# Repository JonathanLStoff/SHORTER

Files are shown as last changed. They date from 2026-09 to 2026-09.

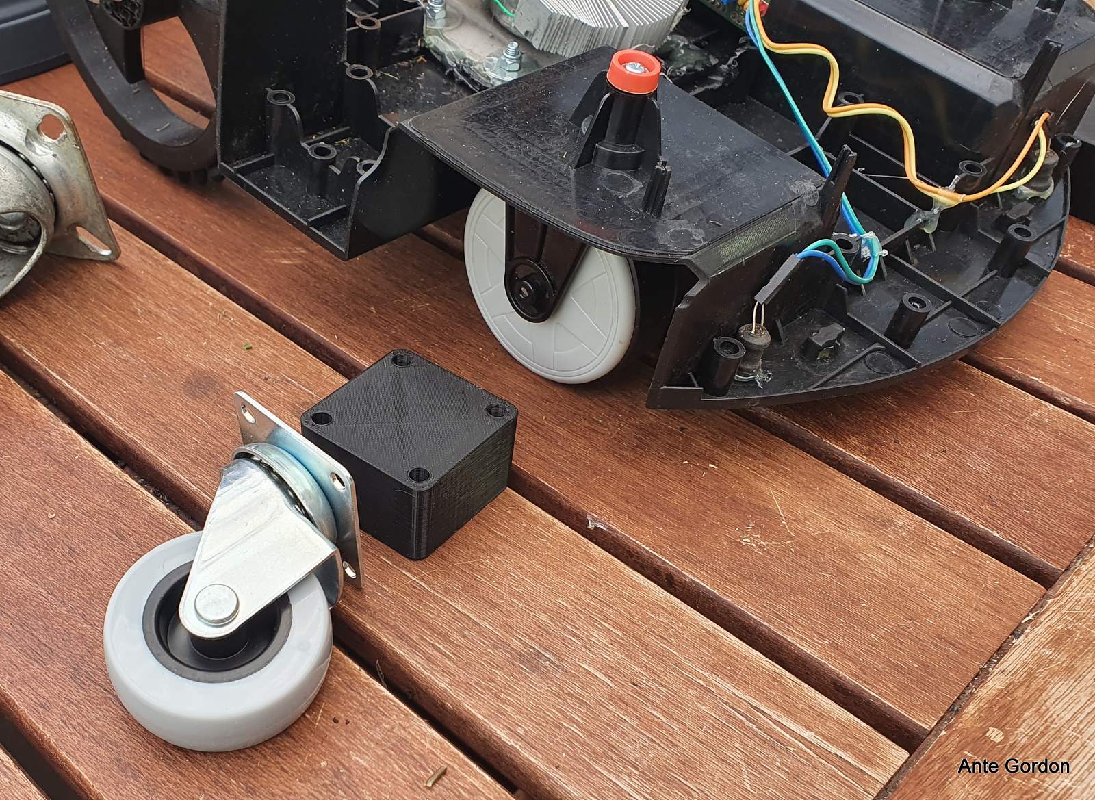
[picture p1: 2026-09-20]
reference/Husqvarna automower mini distanse for Ikea rill wheel - 5445815/images/20220730_103827-1.jpg

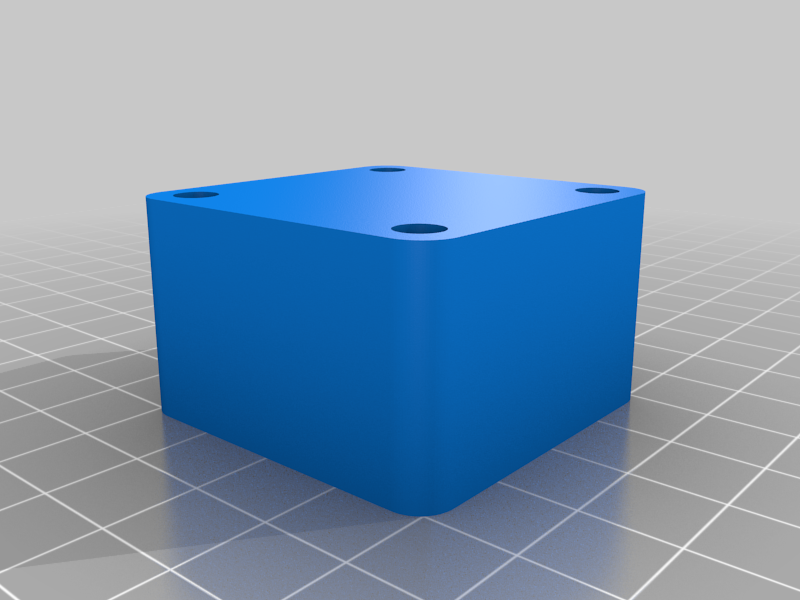
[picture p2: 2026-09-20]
reference/Husqvarna automower mini distanse for Ikea rill wheel - 5445815/images/fr-wheel-rill-25mm.png

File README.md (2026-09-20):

# SHORTER
Sovereign Herbage Ordered Reducer, Trimmer and Eater by Revolution (DIY 3d printable robot lawn mower)

## Possible Parts:

- Acrylic: (dome) https://a.co/d/09qOomaM
- ESP32-C6: https://www.aliexpress.us/item/3256809547014521.html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
- 2x Drive motor TT Motor GM37-3530 or Greartisan 37mm Gear Motor https://www.aliexpress.us/item/3256807619270536.html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
- Blade motor: 12V 775 DC Motor or NFP-RC-545SH https://www.aliexpress.us/item/3256807638419493.html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
- Gyro GY-521 MPU-6050 MPU6050
- 4x+ Bumper: KW12-3 PCB Micro Switch
- Motor controller: BTS7960 https://www.aliexpress.us/item/3256811668284674.html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
- Coil Power Relay DPDT LY2NJ HH62P HHC68A-2Z (fuse?)
- Copper plate for charging
- tinned copper conductor with a thick, high-density polyethylene (HDPE) or heavy-duty PE jacket
- O ring cord 1mm: https://www.aliexpress.us/item/3256812104765869.html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
- filament for waterproof-needing parts (PETG): https://www.amazon.com/SUNLU-Filament-PETG-1-75mm-Stringing/dp/B0FGTQJTM4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
- Buck converter 12v to 5v: https://www.aliexpress.us/item/3256808617601570.html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
- Blades https://a.co/d/00TkhfZo
### Triangulation module:
- NEO-6M GPS Module
- 4x CC1101 915 MHz RF Transceiver Module (1 for robot, 3 for in triangulation)
- 3x ESP32-C3 (For indoor use) https://www.aliexpress.us/item/3256807018729495.html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

### Base Station finder module:
- ESP-32 kit with OV2640: https://www.aliexpress.us/item/3256808099197404.html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
(also using the cc1101 for this)
### Base Station:
- 14.6V 10A LiFePO4 Battery Charger https://a.co/d/04Ycegk0
- QR code
- CC1101 915 MHz RF Transceiver Module
- ESP32-C3 https://www.aliexpress.us/item/3256807018729495.html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
- Acrylic: (dome) https://a.co/d/09qOomaM

### Extras that might be useful:
- Sonic sensor: HC-SR04 HCSR04 (distance sensor/material sensor)
- Wired connectors screws: https://a.co/d/0j6jmUwY || https://www.aliexpress.com/ssr/300000512/BundleDeals2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

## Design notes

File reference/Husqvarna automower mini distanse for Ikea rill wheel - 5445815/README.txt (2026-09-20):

Husqvarna automower mini distanse for Ikea rill wheel by Gigante on Thingiverse: https://www.thingiverse.com/thing:5445815

Summary:
Spacer 25 or 30mm to replace the original caster wheels on the automower toy with Ikea Rill -link wheel. I moved the Liam DIY robotic lawnmower from the 4l food container to the automower RC toy. I had to get more hight due to the small rear wheels (165mm in diameter), and compensate to lift the mower in the front.

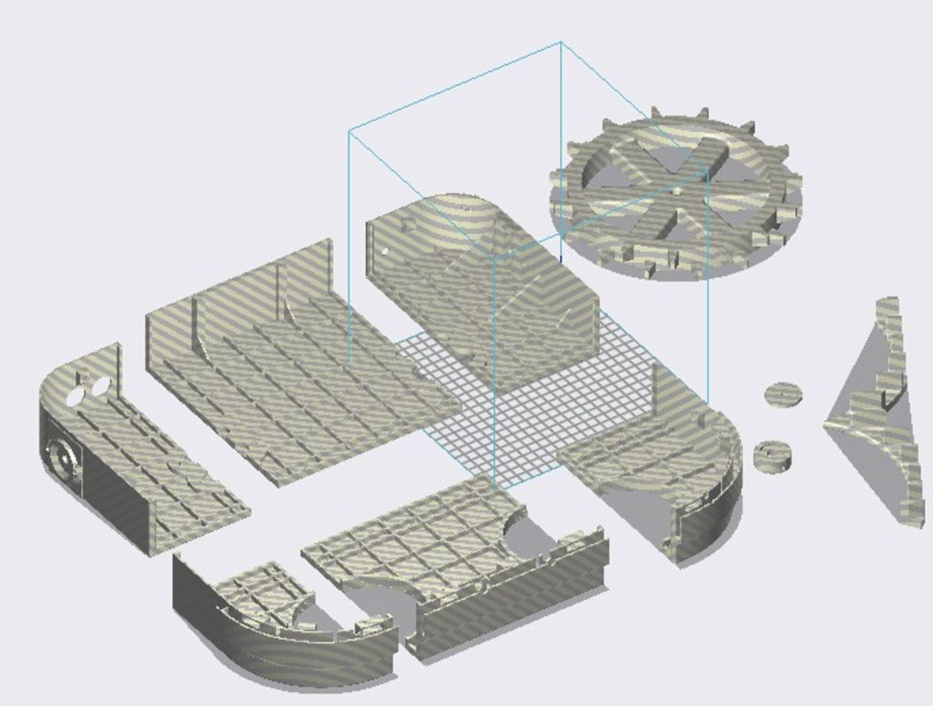
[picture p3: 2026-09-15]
reference/Screenshot 2026-09-14 at 8.23.12 PM.png

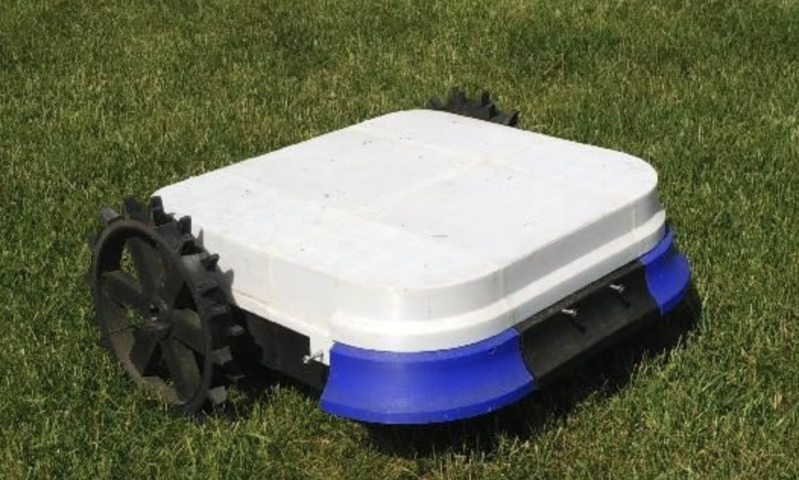
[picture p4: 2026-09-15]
reference/Screenshot 2026-09-14 at 8.22.39 PM.png

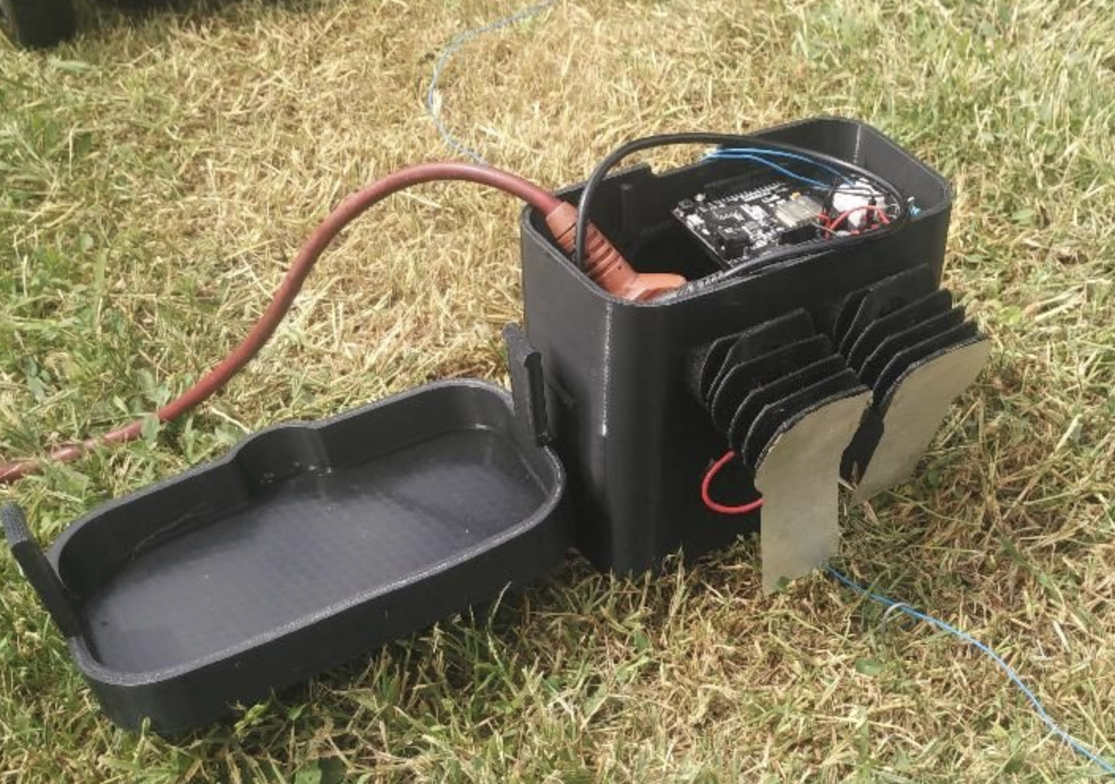
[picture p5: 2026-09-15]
reference/Screenshot 2026-09-14 at 8.23.23 PM.png

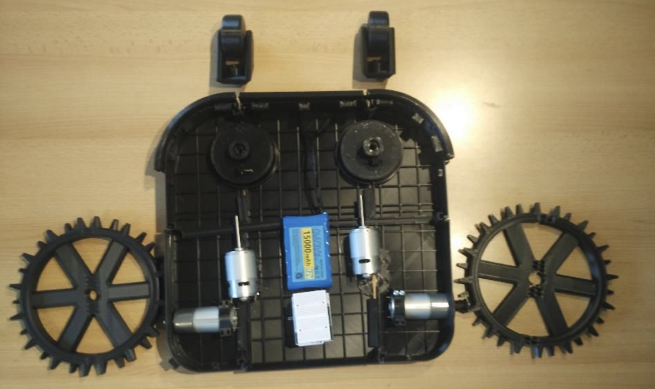
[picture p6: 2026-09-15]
reference/Screenshot 2026-09-14 at 8.23.05 PM.png

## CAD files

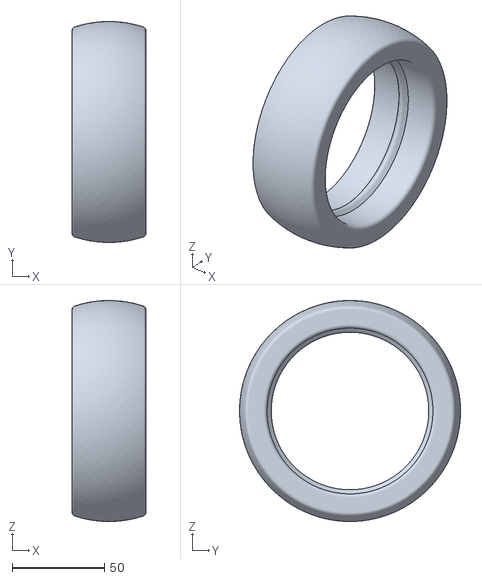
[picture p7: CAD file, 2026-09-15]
reference/ardumower-robotic-lawnmower-25cm-frontwheel-and-12cm-backwheel-model_files/hinterradv1-reifen.stl
40.0 x 120.0 x 120.0

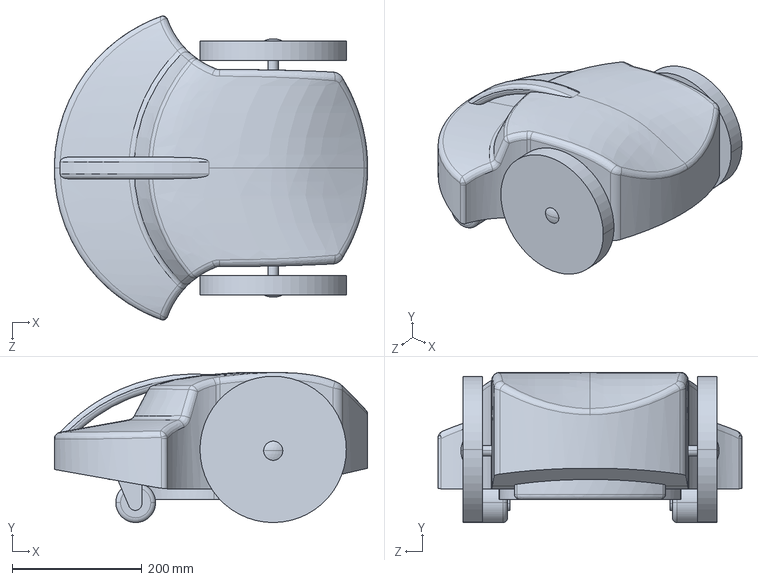
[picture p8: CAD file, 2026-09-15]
reference/fullrobot/Robot mower.STEP
483.9 x 231.8 x 469.4 mm

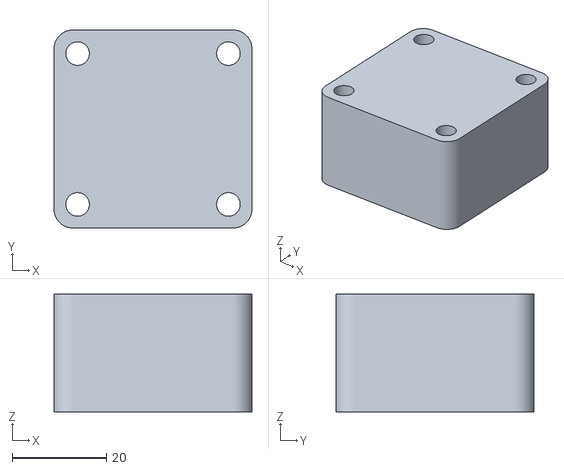
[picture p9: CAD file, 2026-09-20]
reference/Husqvarna automower mini distanse for Ikea rill wheel - 5445815/files/fr-wheel-rill-25mm.stl
42.0 x 42.0 x 25.0

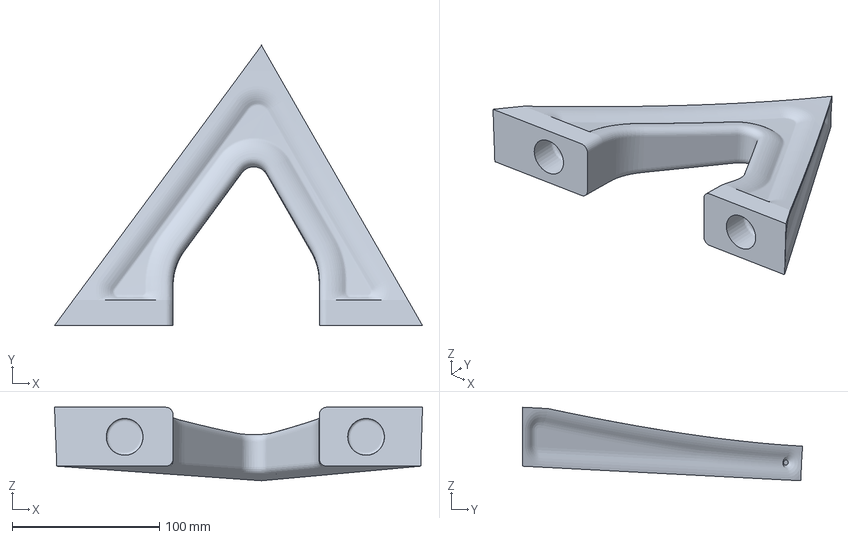
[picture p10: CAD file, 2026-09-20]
reference/mini garage/BASE HOLLOW/base en triangulo HOLLOW L.3mf
250.0 x 190.3 x 50.0 mm

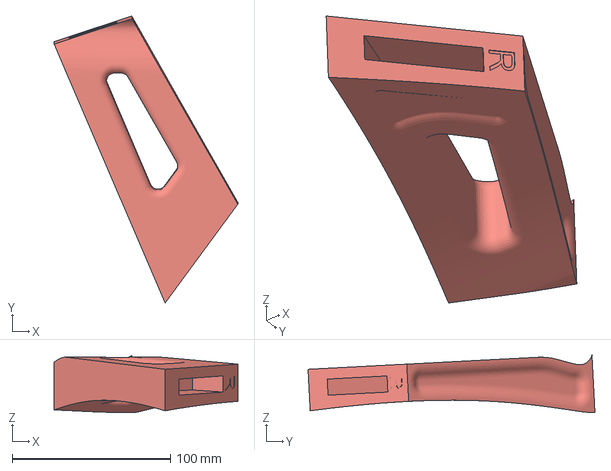
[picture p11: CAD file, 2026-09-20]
reference/mini garage/brazo hueco R.3mf
116.0 x 181.3 x 36.1 mm

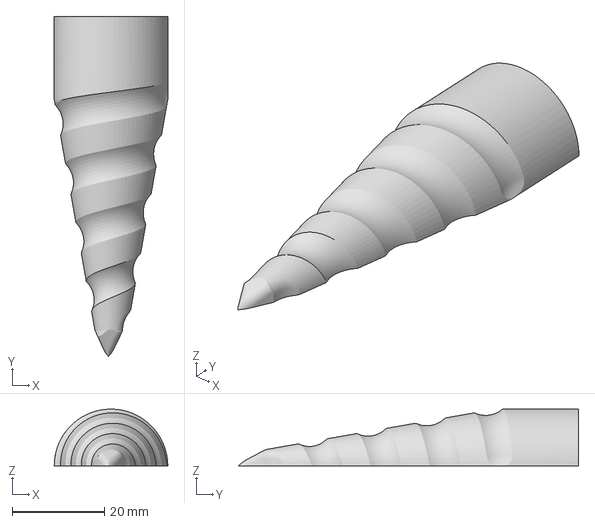
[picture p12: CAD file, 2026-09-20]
reference/mini garage/supports wall or soil/LAWN/TORNILLO GRASS MITAD 2.3mf
24.6 x 73.6 x 12.3 mm

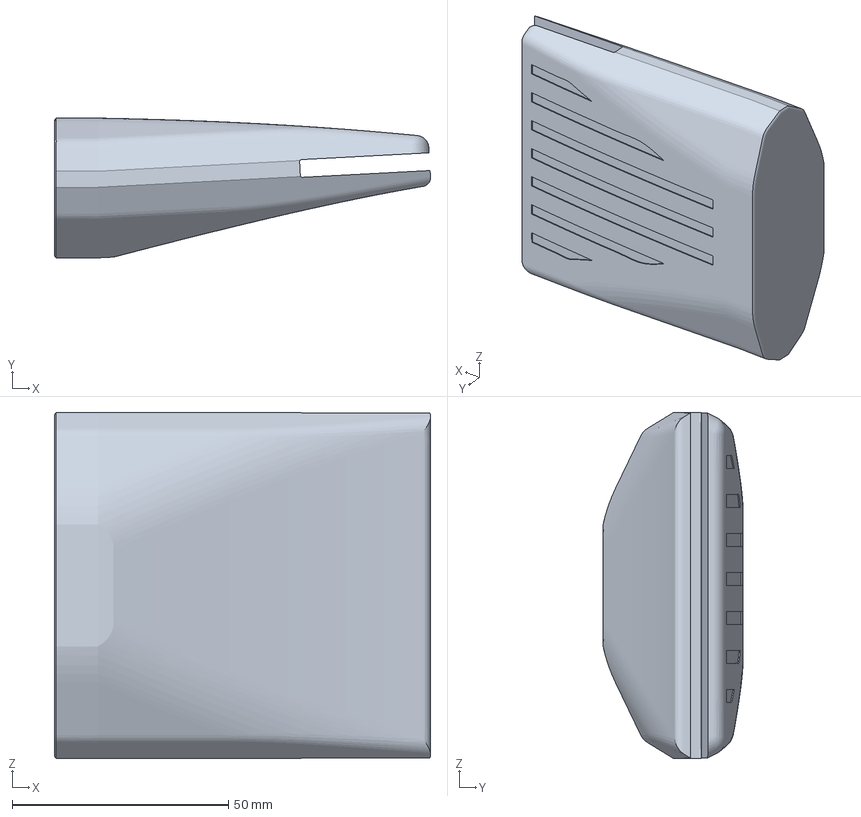
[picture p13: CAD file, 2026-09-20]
reference/mini garage/supports wall or soil/WALL/WALL SUPPORT .3mf
86.9 x 32.3 x 80.0 mm

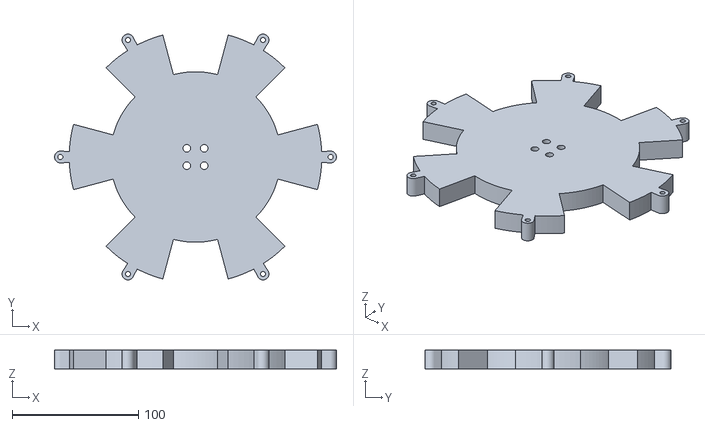
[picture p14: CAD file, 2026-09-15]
reference/ardumower-robotic-lawnmower-25cm-frontwheel-and-12cm-backwheel-model_files/radv2-felge.stl
223.3 x 194.7 x 15.0

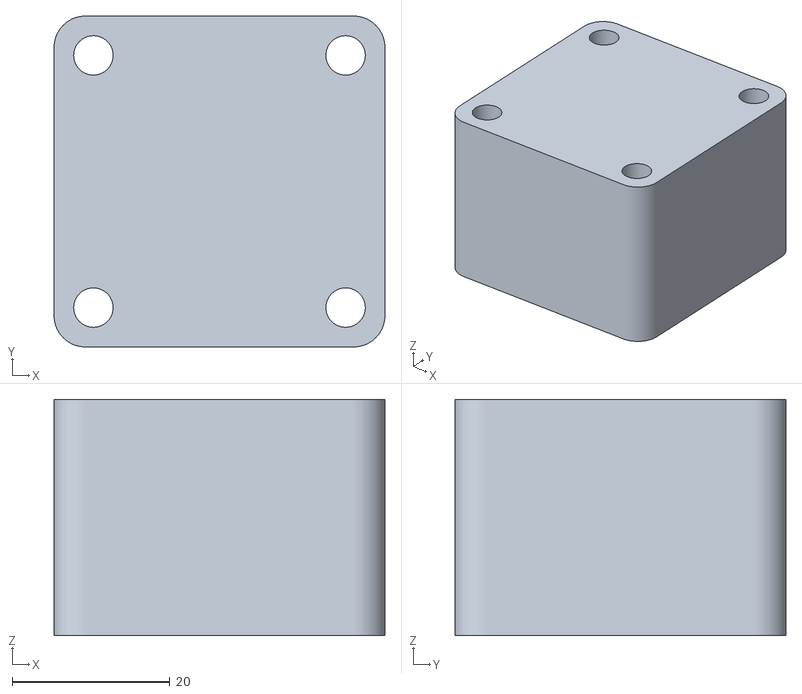
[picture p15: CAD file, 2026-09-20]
reference/Husqvarna automower mini distanse for Ikea rill wheel - 5445815/files/fr-wheel-rill-30mm.stl
42.0 x 42.0 x 30.0

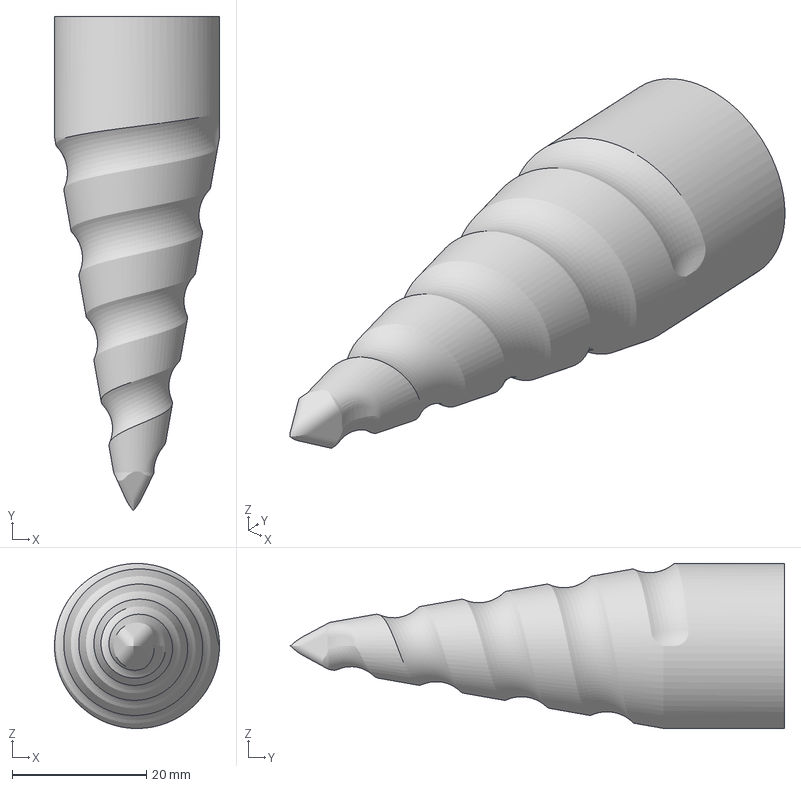
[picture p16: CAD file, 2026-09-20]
reference/mini garage/supports wall or soil/LAWN/TORNILLO GRASS COMPLETO .3mf
24.6 x 73.6 x 24.6 mm

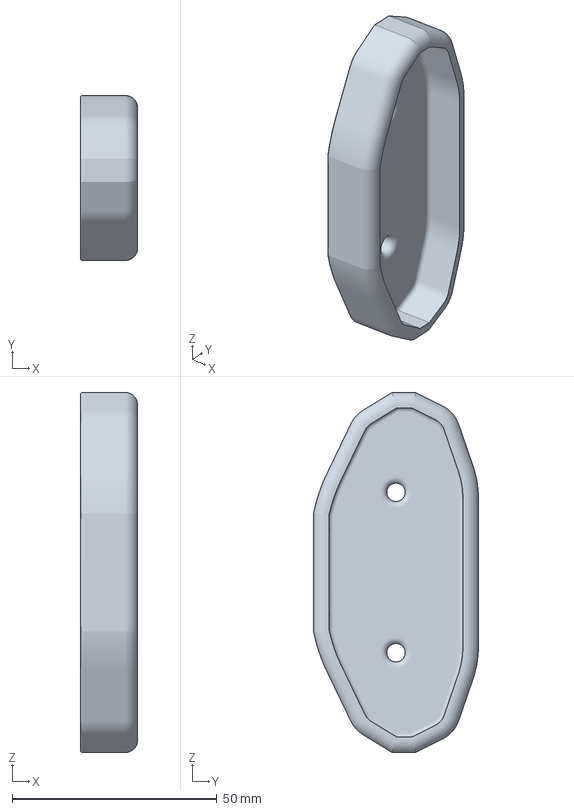
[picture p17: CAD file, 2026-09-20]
reference/mini garage/supports wall or soil/WALL/wall support base.3mf
14.0 x 40.3 x 88.0 mm

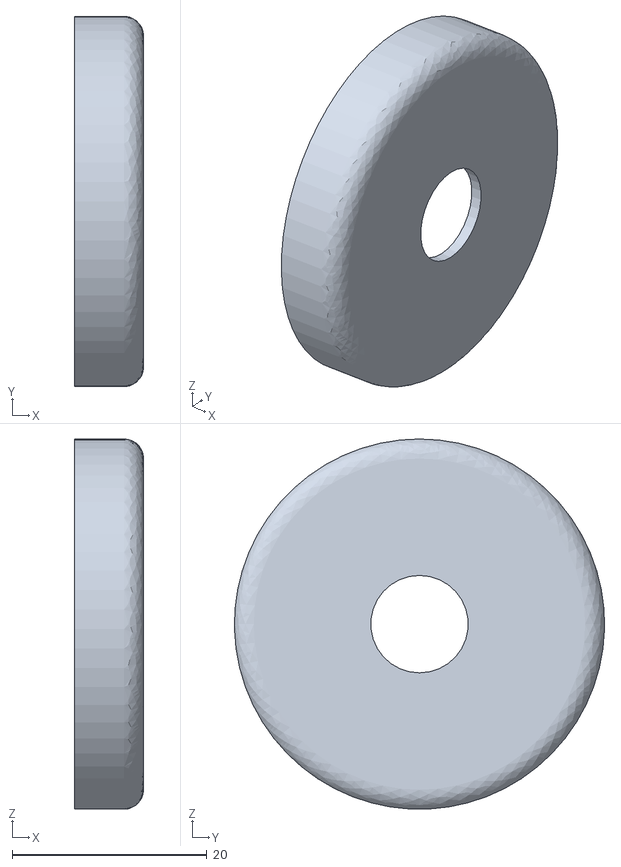
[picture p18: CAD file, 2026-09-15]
reference/ardumower-robotic-lawnmower-25cm-frontwheel-and-12cm-backwheel-model_files/hinterradv1-kappe.stl
7.10 x 38.0 x 38.0

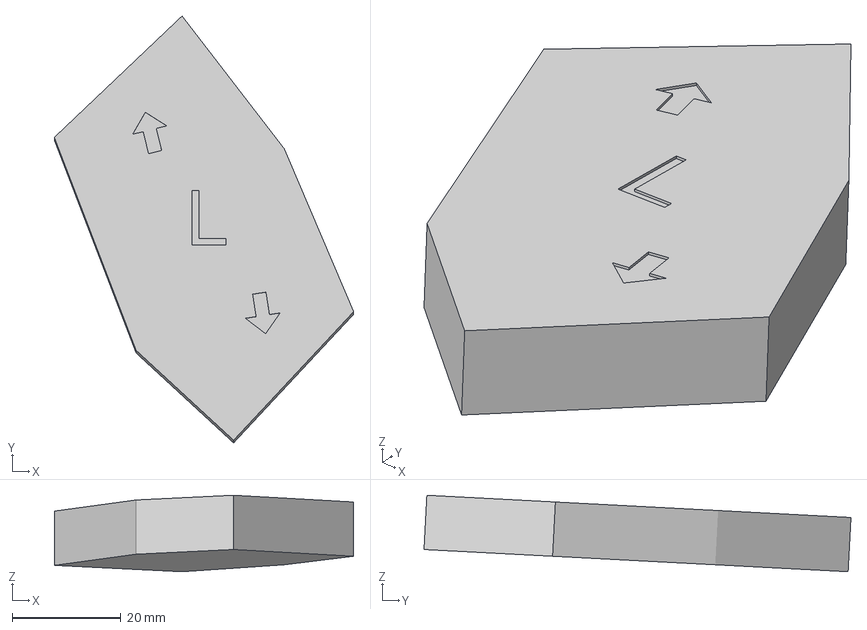
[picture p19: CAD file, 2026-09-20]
reference/mini garage/click de seguridad L.3mf
55.1 x 78.6 x 14.1 mm

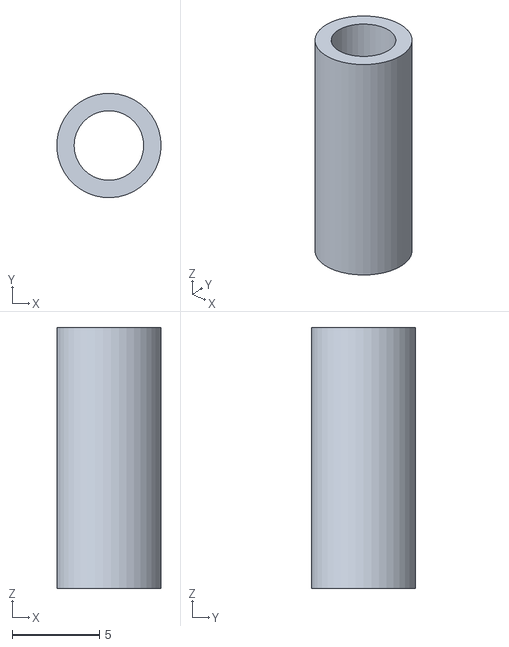
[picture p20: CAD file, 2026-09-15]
reference/ardumower-robotic-lawnmower-25cm-frontwheel-and-12cm-backwheel-model_files/radv2-hulse.stl
5.99 x 6.00 x 15.0

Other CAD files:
reference/mini garage/BASE HOLLOW/base en triangulo HOLLOW R.3mf
reference/mini garage/brazo hueco L.3mf
reference/mini garage/supports wall or soil/LAWN/TORNILLO GRASS MITAD 1.3mf
reference/mini garage/click de seguridad R.3mf
reference/ardumower-robotic-lawnmower-25cm-frontwheel-and-12cm-backwheel-model_files/hinterradv1-felge.stl
reference/ardumower-robotic-lawnmower-25cm-frontwheel-and-12cm-backwheel-model_files/radv2-bolzen.stl
reference/ardumower-robotic-lawnmower-25cm-frontwheel-and-12cm-backwheel-model_files/radv2-klammer.stl
reference/ardumower-robotic-lawnmower-25cm-frontwheel-and-12cm-backwheel-model_files/radv2-reifen.stl
reference/fullrobot/Robot mower.IGS
reference/fullrobot/Robot mower.SLDPRT
reference/fullrobot/Robot mower.x_t
reference/mini garage/1946.3mf
reference/mini garage/BASE MINI L.3mf
reference/mini garage/BASE MINI R.3mf
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

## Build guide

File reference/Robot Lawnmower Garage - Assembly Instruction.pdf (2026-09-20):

## Robot Lawnmower Garage

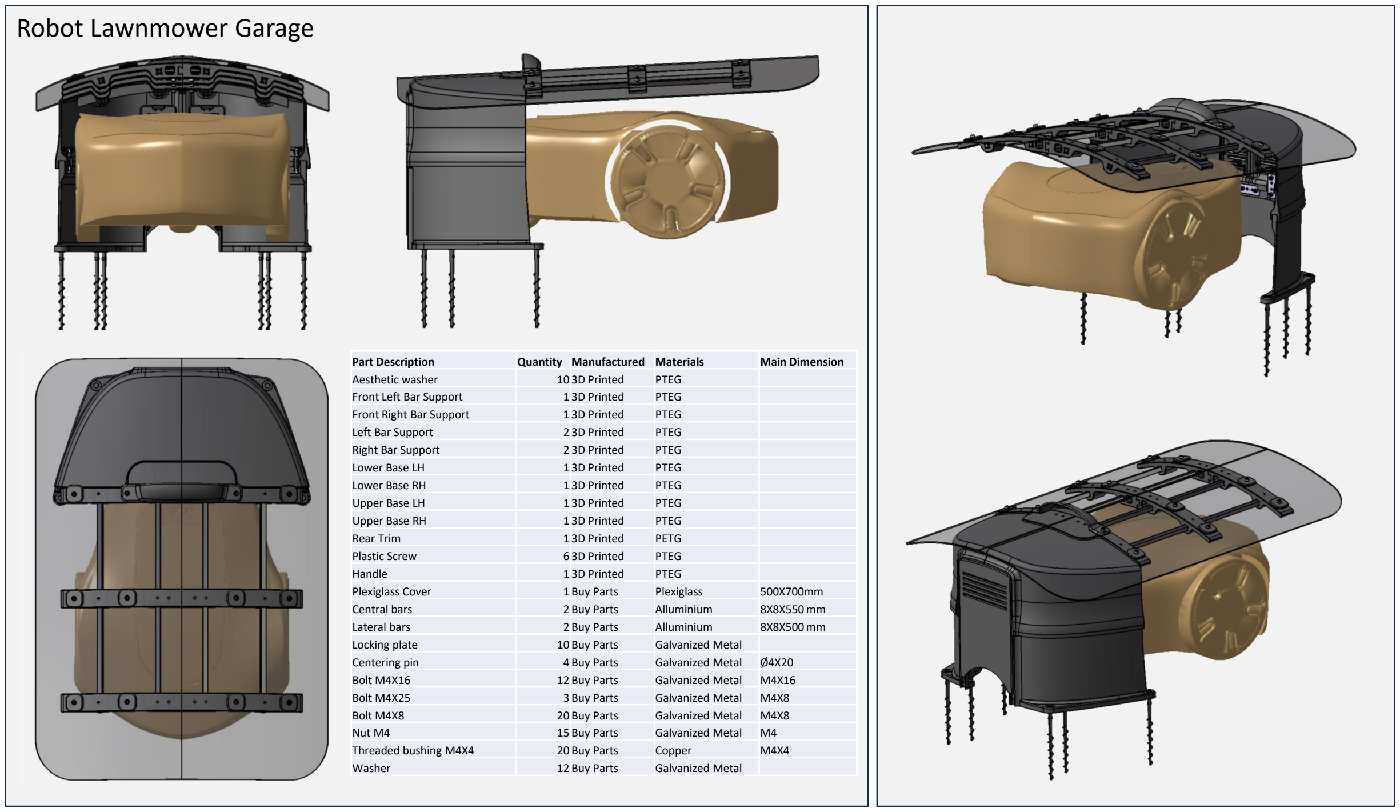
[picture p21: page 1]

Part Description | Quantity | Manufactured | Materials | Main Dimension
Aesthetic washer | 10 3D Printed | | PTEG
Front Left Bar Support | 1 3D Printed | | PTEG
Front Right Bar Support | 1 3D Printed | | PTEG
Left Bar Support | 2 3D Printed | | PTEG
Right Bar Support | 2 3D Printed | | PTEG
Lower Base LH | 1 3D Printed | | PTEG
Lower Base RH | 1 3D Printed | | PTEG
Upper Base LH | 1 3D Printed | | PTEG
Upper Base RH | 1 3D Printed | | PTEG
Rear Trim | 1 3D Printed | | PETG
Plastic Screw | 6 3D Printed | | PTEG
Handle | 1 3D Printed | | PTEG
Plexiglass Cover | 1 Buy Parts | | Plexiglass | 500X700mm
Central bars | 2 Buy Parts | | Alluminium | 8X8X550 mm
Lateral bars | 2 Buy Parts | | Alluminium | 8X8X500 mm
Locking plate | 10 Buy Parts | | Galvanized Metal
Centering pin | 4 Buy Parts | | Galvanized Metal | Ø4X20
Bolt M4X16 | 12 Buy Parts | | Galvanized Metal | M4X16
Bolt M4X25 | 3 Buy Parts | | Galvanized Metal | M4X8
Bolt M4X8 | 20 Buy Parts | | Galvanized Metal | M4X8
Nut M4 | 15 Buy Parts | | Galvanized Metal | M4
Threaded bushing M4X4 | 20 Buy Parts | | Copper | M4X4
Washer | 12 Buy Parts | | Galvanized Metal

## ROOF

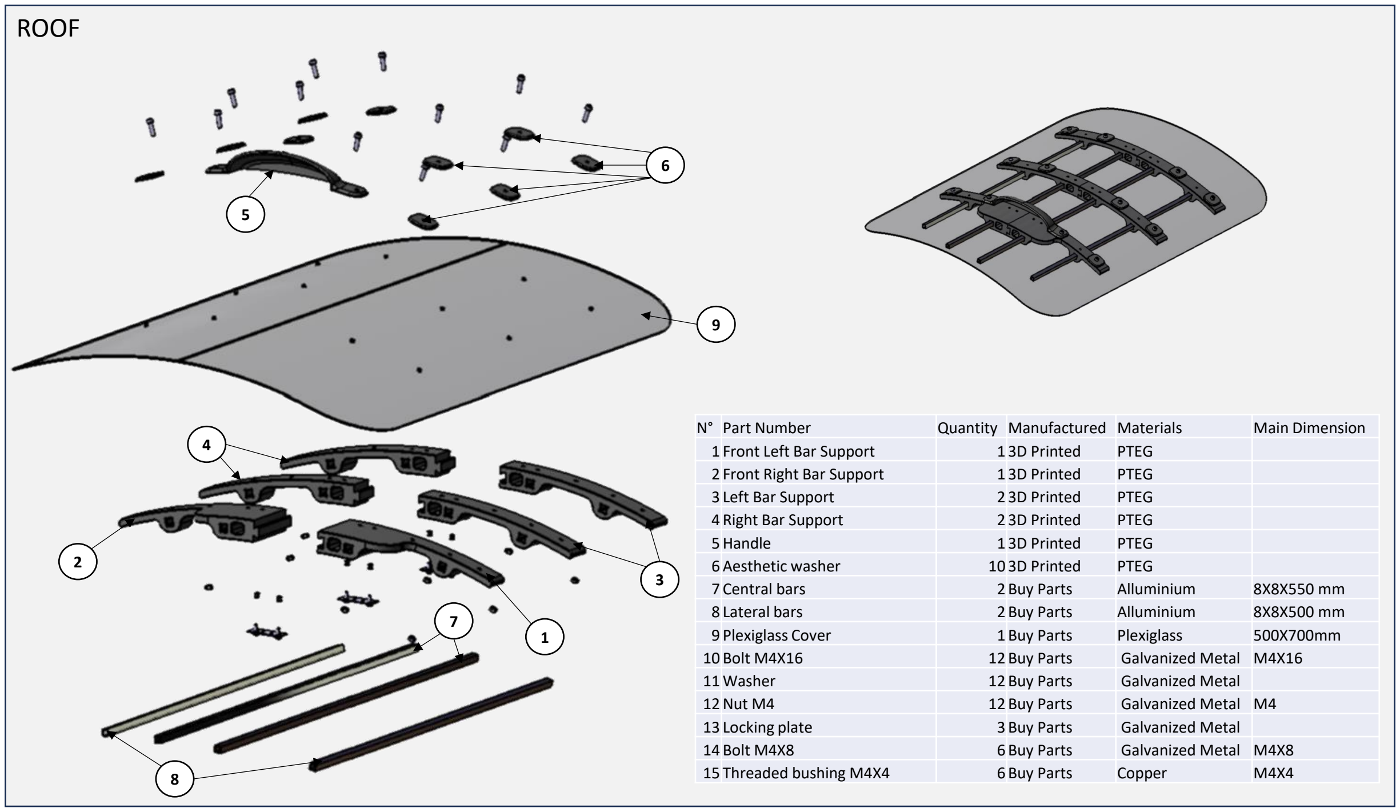
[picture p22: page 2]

N° | Part Number | Quantity | Manufactured | Materials | Main Dimension
1 Front Left Bar Support | | 1 3D Printed | | PTEG
2 Front Right Bar Support | | 1 3D Printed | | PTEG
3 Left Bar Support | | 2 3D Printed | | PTEG
4 Right Bar Support | | 2 3D Printed | | PTEG
5Handle | | 1 3D Printed | | PTEG
6 Aesthetic washer | | 10 3D Printed | | PTEG
7 Central bars | | 2 Buy Parts | | Alluminium | 8X8X550 mm
8 Lateral bars | | 2 Buy Parts | | Alluminium | 8X8X500 mm
9 Plexiglass Cover | | 1 Buy Parts | | Plexiglass | 500X700mm
10 Bolt M4X16 | | 12 Buy Parts | | Galvanized Metal | M4X16
11 Washer | | 12 Buy Parts | | Galvanized Metal
12Nut M4 | | 12 Buy Parts | | Galvanized Metal | M4
13 Locking plate | | 3 Buy Parts | | Galvanized Metal
14 Bolt M4X8 | | 6 Buy Parts | | Galvanized Metal | M4X8
15 Threaded bushing M4X4 | | 6 Buy Parts | | Copper | M4X4

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
## Phase 1.1

## Phase 1.2

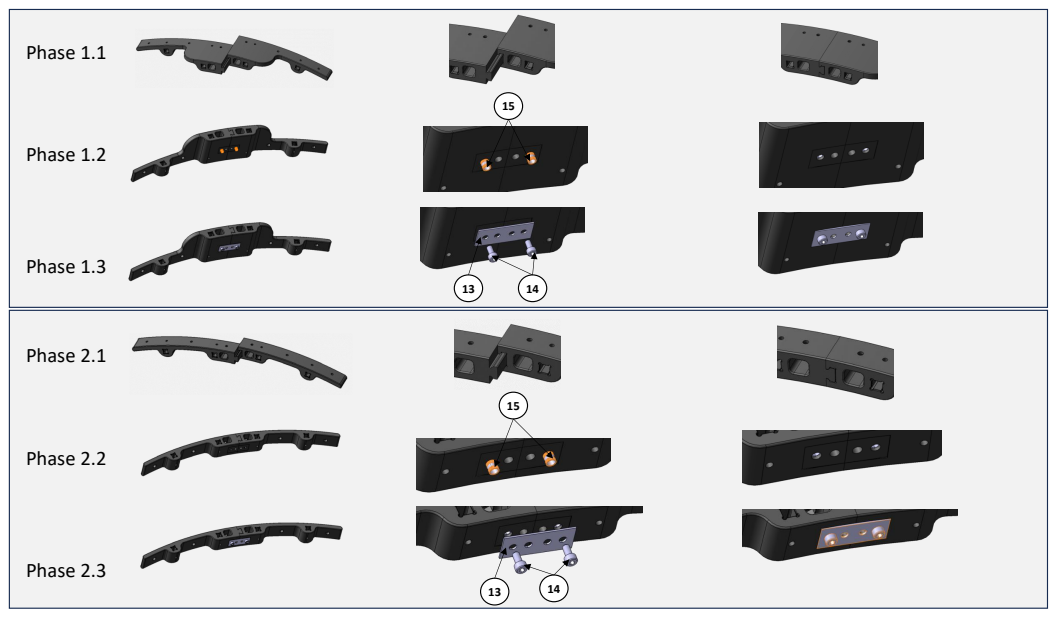
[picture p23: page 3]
Phase 2.1; Phase 2.2; Phase 2.3; Phase 1.3

## Phase 3.1

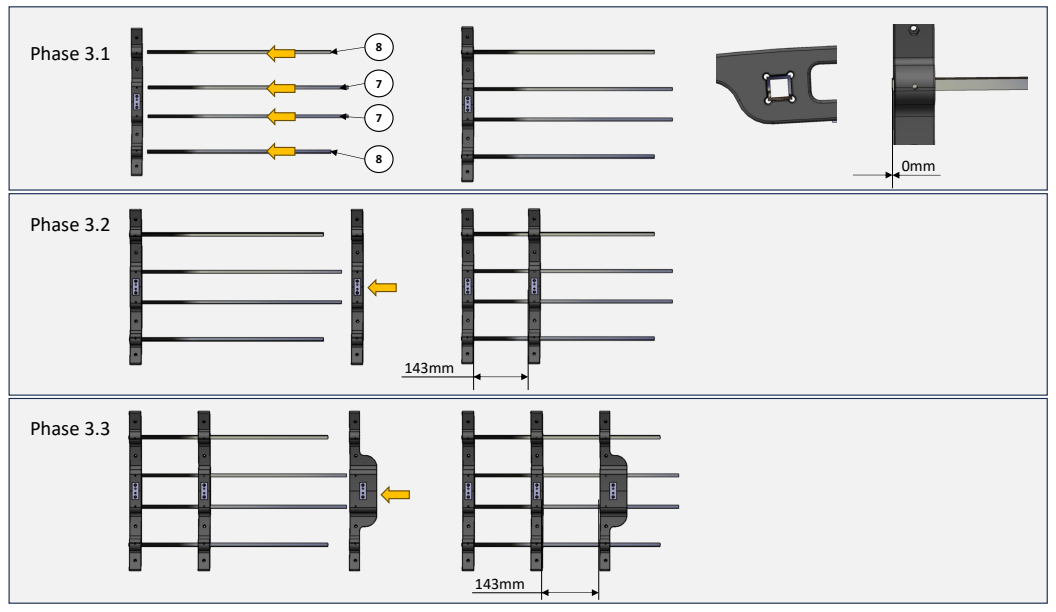
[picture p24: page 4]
Phase 3.2; Phase 3.3

## Phase 4

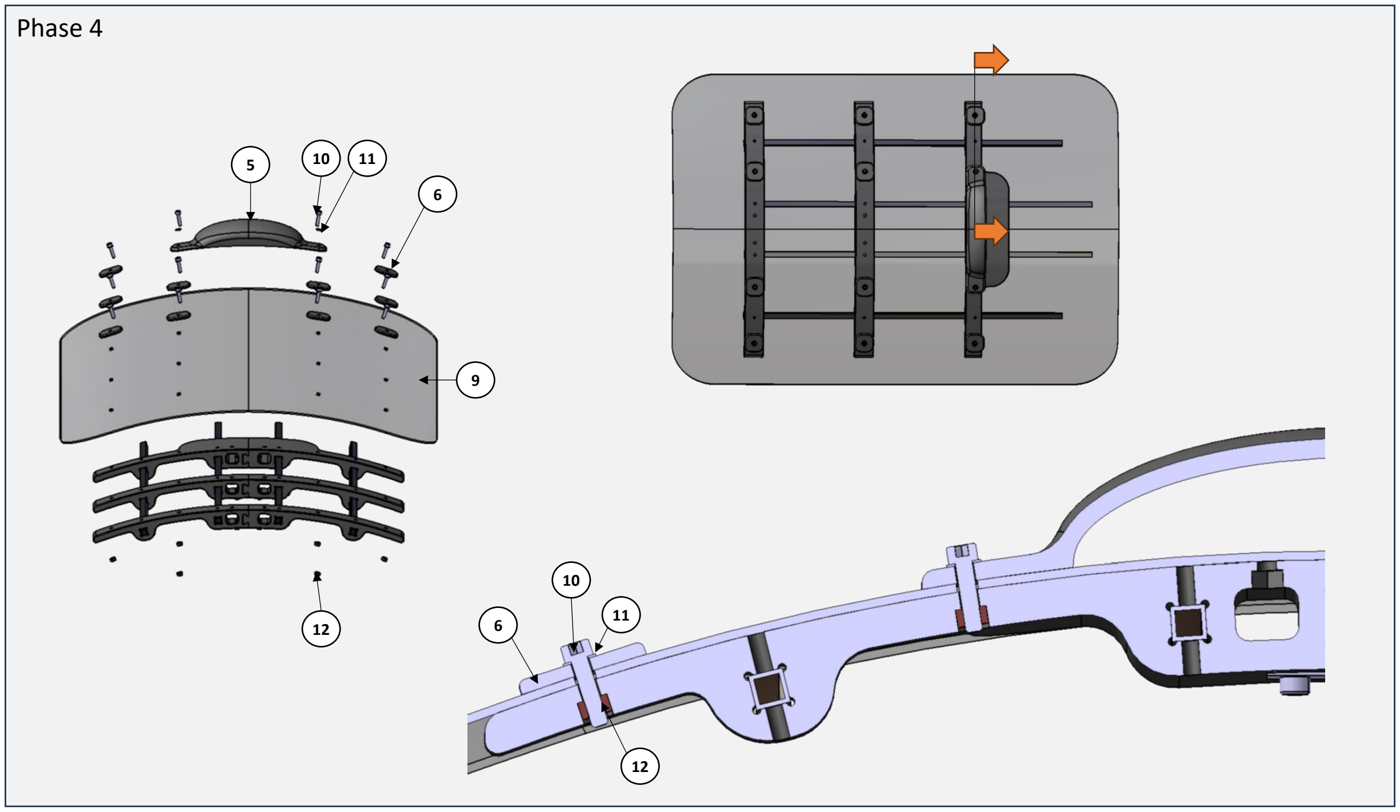
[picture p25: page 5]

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
## Lower Base

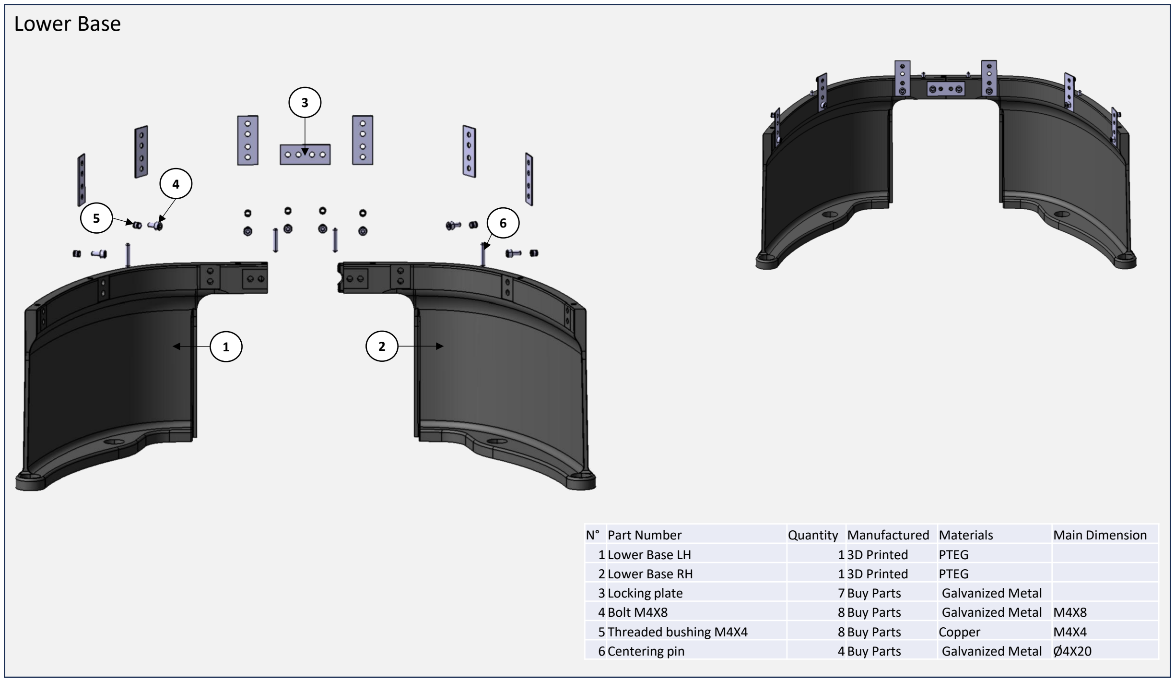
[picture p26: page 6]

N° | Part Number | Quantity | Manufactured | Materials | Main Dimension
1 Lower Base LH | | 1 3D Printed | | PTEG
2 Lower Base RH | | 1 3D Printed | | PTEG
3 Locking plate | | 7 Buy Parts | | Galvanized Metal
4 Bolt M4X8 | | 8 Buy Parts | | Galvanized Metal | M4X8
5 Threaded bushing M4X4 | | 8 Buy Parts | | Copper | M4X4
6 Centering pin | | 4 Buy Parts | | Galvanized Metal | Ø4X20

1 2

3

4

5 6

Phase 5 | Phase 5.1 X 4 | Phase 5.2 X 2

## Lower Base LH

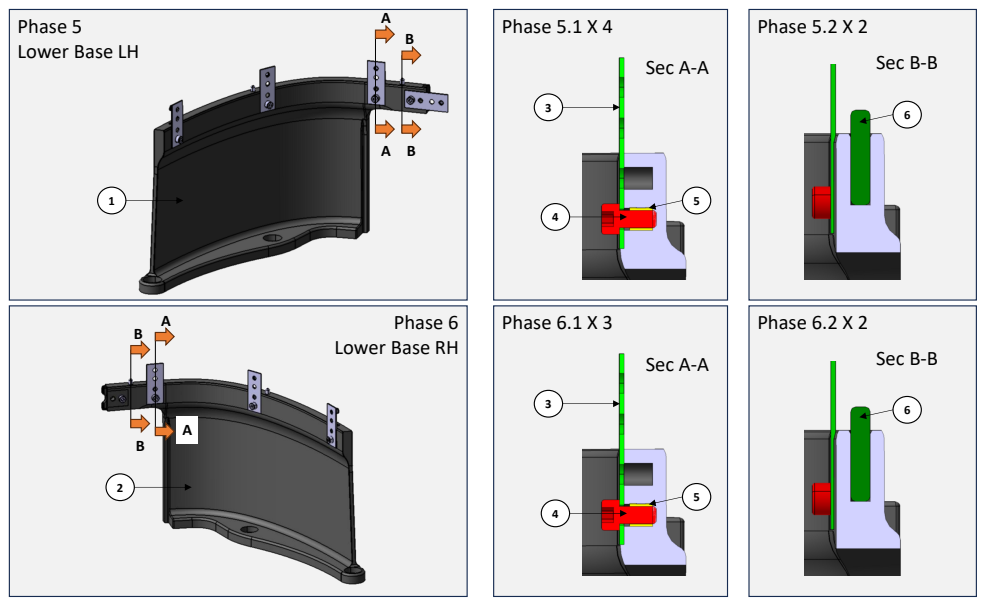
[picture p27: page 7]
Sec A-A; Sec B-B; Phase 6.1 X 3; Phase 6.2 X 2

Phase 6
Lower Base RH

## Phase 7 Lower Base

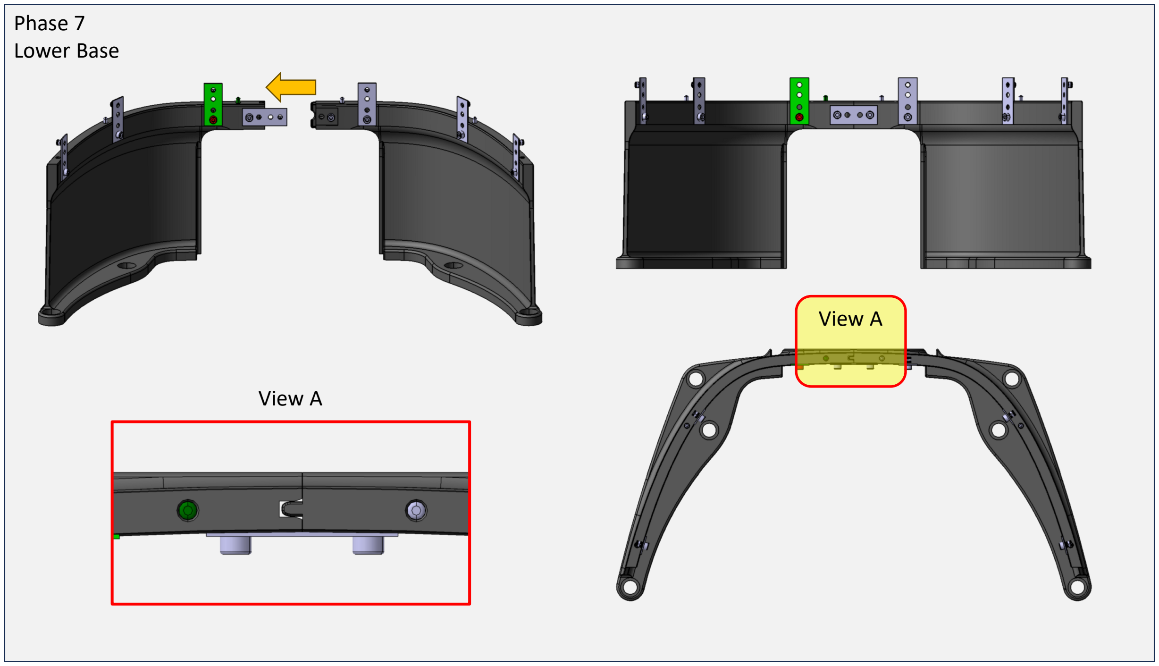
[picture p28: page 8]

## View A

## View A

## Upper Base

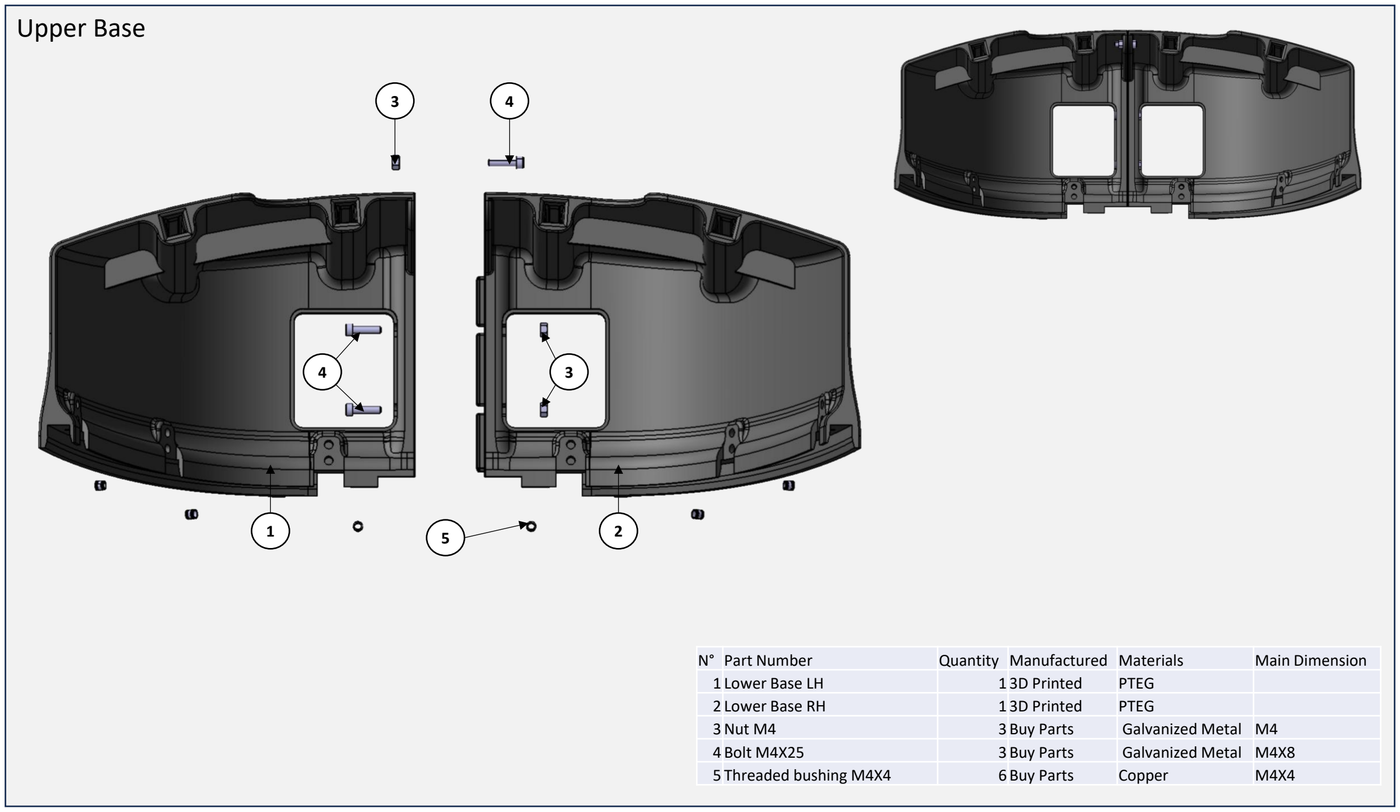
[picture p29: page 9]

N° | Part Number | Quantity | Manufactured | Materials | Main Dimension
1 Lower Base LH | | 1 3D Printed | | PTEG
2 Lower Base RH | | 1 3D Printed | | PTEG
3Nut M4 | | 3 Buy Parts | | Galvanized Metal | M4
4 Bolt M4X25 | | 3 Buy Parts | | Galvanized Metal | M4X8
5 Threaded bushing M4X4 | | 6 Buy Parts | | Copper | M4X4

1 2

3

5

3

4

4

Phase 8 | Phase 8.1 X 3

## Upper Base LH

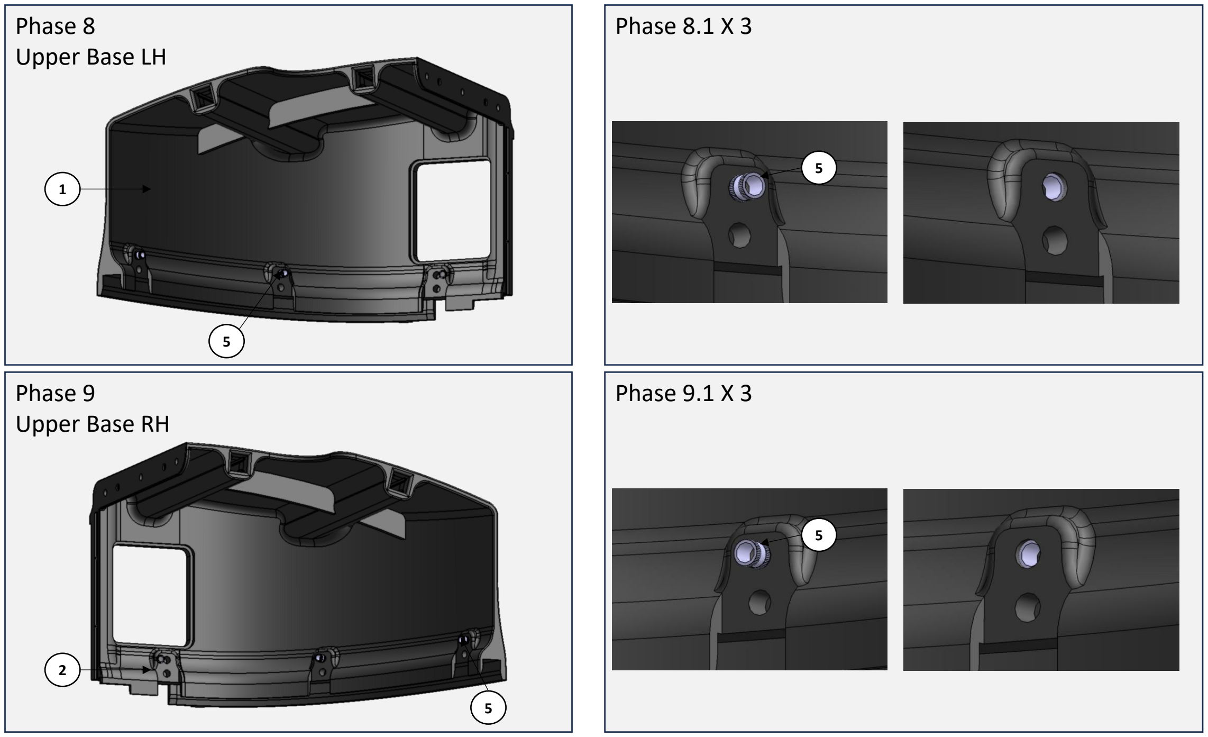
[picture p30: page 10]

5

## Phase 9 Upper Base RH

1

5

## Phase 9.1 X 3

5

2

5

## Phase 10 Upper Base

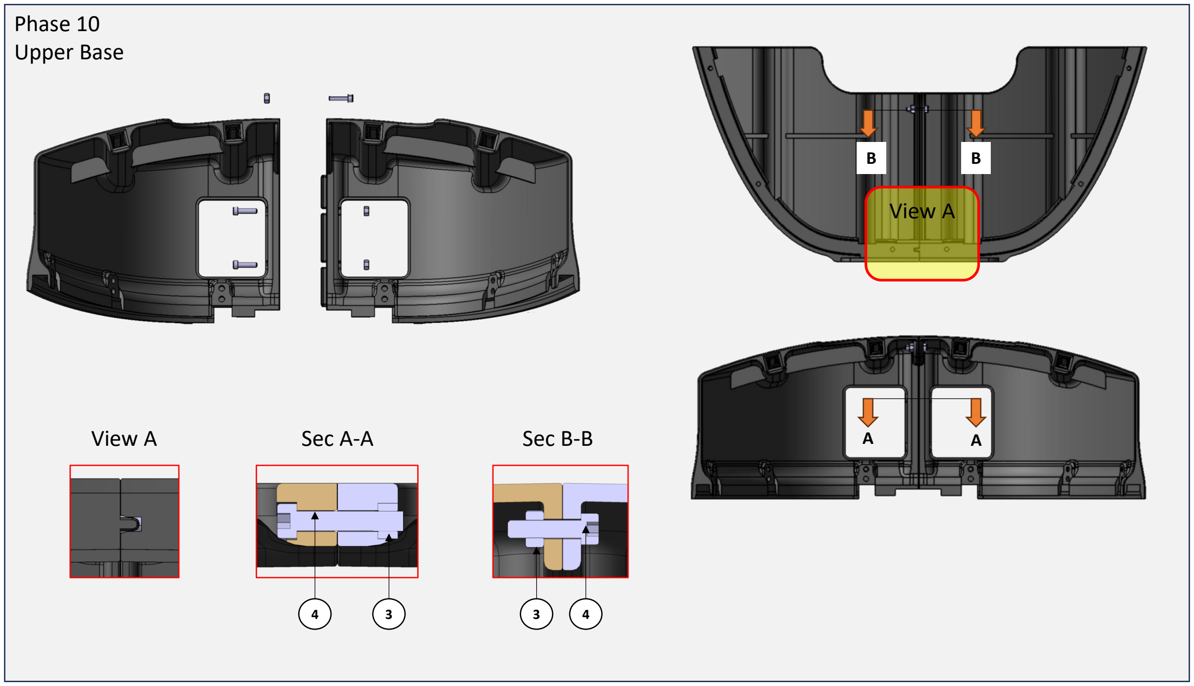
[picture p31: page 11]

## View A

## View A

A A

B B

Sec A-A | Sec B-B
4 | 3 | 3 | 4

## Phase 11 BASE

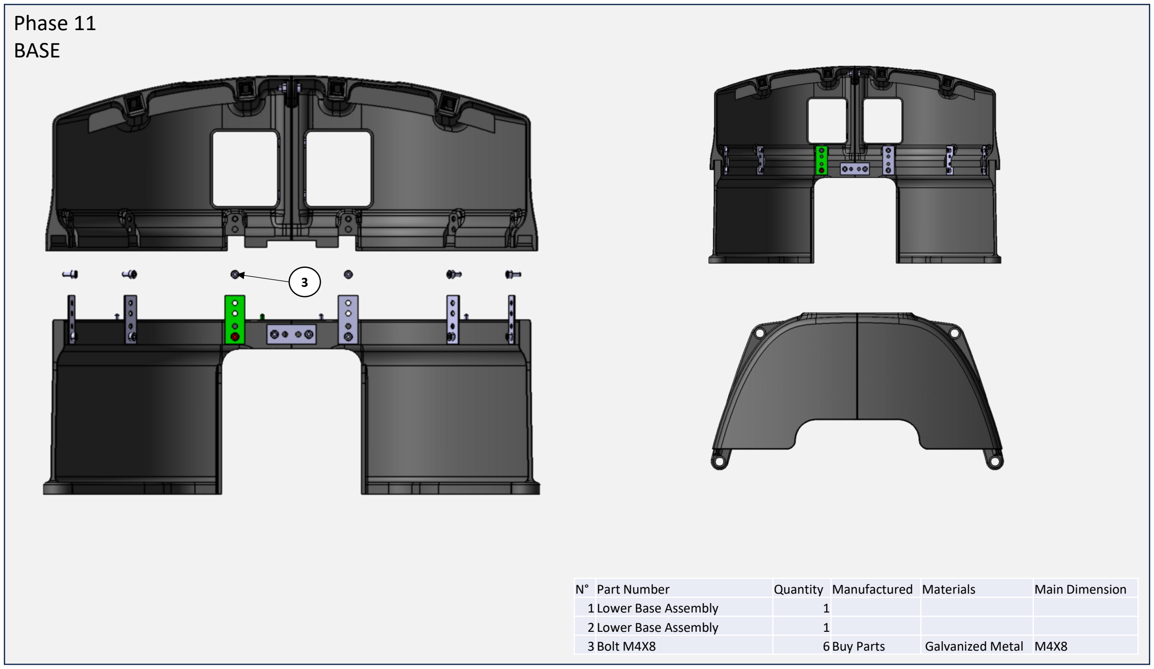
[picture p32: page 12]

N° | Part Number | Quantity | Manufactured | Materials | Main Dimension
1 Lower Base Assembly | | 1
2 Lower Base Assembly | | 1
3 Bolt M4X8 | | 6 Buy Parts | | Galvanized Metal | M4X8

3

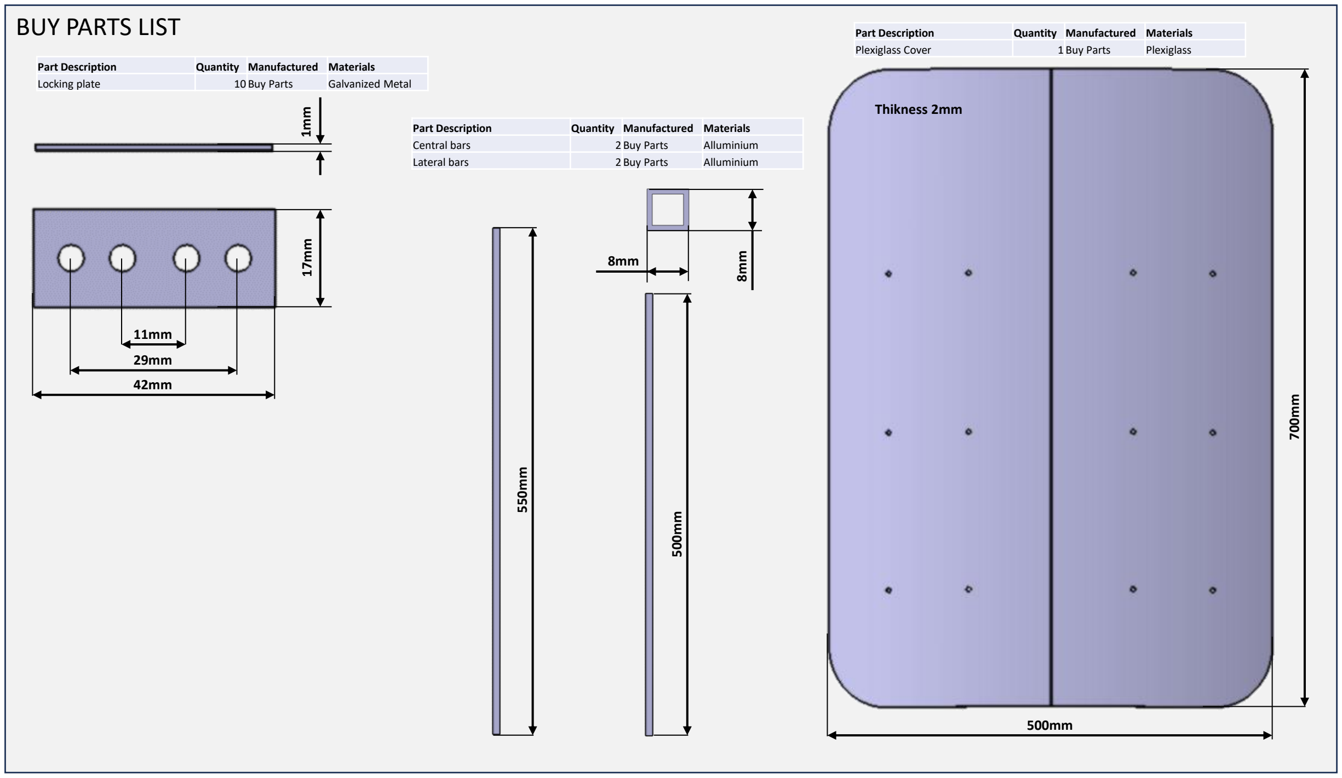
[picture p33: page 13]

BUY PARTS LIST | Part Description | Quantity | Manufactured | Materials
Plexiglass Cover | 1 Buy Parts | Plexiglass

11mm

29mm
42mm

17mm

Part Description | Quantity | Manufactured | Materials
Locking plate | 10 Buy Parts | Galvanized Metal 1mm

500mm

500mm

Thikness 2mm

700mm

550mm

Part Description | Quantity | Manufactured | Materials
Central bars | 2 Buy Parts | | Alluminium
Lateral bars | 2 Buy Parts | Alluminium8mm

8mm

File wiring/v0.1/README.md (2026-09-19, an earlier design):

# WireViz files — boundary robot

These diagrams are split into reusable electrical modules.

## Reused module
`triangulation_anchor.yaml` is intended to be instantiated 3 times:
- TRI-1
- TRI-2
- TRI-3

## Important assumptions
- The ESP32-C6 board is powered from a regulated 5 V rail through its USB/5V input, unless the exact board exposes a suitable VIN pin.
- ESP32-C3 anchor boards use 3.3 V logic.
- CC1101 modules are 3.3 V devices. Do **not** feed a bare CC1101 from 5 V.
- BTS7960 is used as one H-bridge per motor. For two drive motors, use two BTS7960 modules.
- The 775/NFP-RC-545SH blade motor is a high-current 12 V load; its exact current determines battery, fuse, wiring gauge, and BTS7960 suitability.
- The 14.6 V LiFePO4 charger is a charger input, not a logic supply.
- Copper charging plates are shown as the DC charging interface only.
- The relay file treats the LY2NJ/HH62P/HHC68A-2Z as a generic DPDT power relay. Verify the exact socket/terminal numbering on the purchased relay.
- The KW12-3 bumper switches are shown as simple dry-contact switches.
- NEO-6M UART pin names are functional labels; exact ESP32 GPIO assignment is intentionally left as GPIO_* placeholders.
- Pin numbers on generic modules can vary by board/vendor. Verify the silkscreen/datasheet before wiring.

Files:
- `robot_controller.yaml`
- `drive_motor.yaml`
- `blade_motor.yaml`
- `bumper_switch.yaml`
- `bts7960_motor_controller.yaml`
- `dpdt_relay.yaml`
- `charging_plate.yaml`
- `charging_input.yaml`
- `boundary_wire.yaml`
- `triangulation_anchor.yaml`
- `robot_gps_rf.yaml`
- `base_station_finder.yaml`
- `base_station.yaml`
- `sonic_sensor.yaml`

Non-electrical parts (acrylic dome, PETG filament, O-ring cord, QR code) are not useful as standalone WireViz diagrams.

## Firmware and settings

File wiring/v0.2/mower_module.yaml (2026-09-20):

metadata:
  title: Mower Bot
  description: >
    Autonomous mower bot. Main controller is an ESP32-C6.
    An ESP32-CAM with OV2640 acts as the base-station finder
    and forwards detection data to the ESP32-C6 over UART.
    Includes CC1101 915 MHz radio, NEO-6M GPS, MPU-6050 IMU,
    two GM37-3530 drive motors, a 775 DC blade motor, three
    BTS7960 drivers, four KW12-3 bumper switches, an HC-SR04
    ultrasonic sensor, a charging relay, and copper charging
    contacts. Power comes from a LiFePO4 pack via a 5 V buck.

connectors:
  ESP32C6:
    type: ESP32-C6 Dev Board
    pins:
      - 5V_1
      - 5V_2
      - 5V_3
      - 5V_4
      - 5V_5
      - 5V_6
      - 3V3_1
      - 3V3_2
      - 3V3_3
      - 3V3_4
      - 3V3_5
      - GND_1
      - GND_2
      - GND_3
      - GND_4
      - GND_5
      - GND_6
      - GND_7
      - GND_8
      - GND_9
      - GND_10
      - GND_11
      - GPIO0
      - GPIO4
      - GPIO5
      - GPIO6
      - GPIO7
      - GPIO8
      - GPIO9
      - GPIO10
      - GPIO11
      - GPIO12
      - GPIO13
      - GPIO14
      - GPIO15
      - GPIO16
      - GPIO17
      - GPIO18
      - GPIO19
      - GPIO20
      - GPIO21
      - GPIO22
      - GPIO23
      - GPIO24
      - GPIO25
      - GPIO26
      - GPIO27
      - GPIO28
      - GPIO29
      - GPIO30

  CAM:
    type: ESP32-CAM with OV2640 (Base Finder)
    pins: [5V, GND, TX, RX]

  CC1101:
    type: CC1101 915 MHz RF Transceiver
    pins: [VCC, GND, SI, SO, SCLK, CSN, GDO0, GDO2]

  GPS:
    type: NEO-6M GPS Module
    pins: [VCC, GND, TX, RX]

  IMU:
    type: GY-521 MPU-6050
    pins: [VCC, GND, SDA, SCL]

  SONAR:
    type: HC-SR04 Ultrasonic Sensor
    pins: [VCC, GND, TRIG, ECHO]

  BUMPERS:
    type: 4x KW12-3 Micro Switch Array
    pins: [SW1, SW2, SW3, SW4, GND]

  BTS_L:
    type: BTS7960 (Left Drive Motor Driver)
    pins: [VCC, GND, R_EN, L_EN, RPWM, LPWM, B+, B-, M+, M-]

  BTS_R:
    type: BTS7960 (Right Drive Motor Driver)
    pins: [VCC, GND, R_EN, L_EN, RPWM, LPWM, B+, B-, M+, M-]

  BTS_B:
    type: BTS7960 (Blade Motor Driver)
    pins: [VCC, GND, R_EN, L_EN, RPWM, LPWM, B+, B-, M+, M-]

  MOT_L:
    type: GM37-3530 Drive Motor (Left)
    pins: [M+, M-]

  MOT_R:
    type: GM37-3530 Drive Motor (Right)
    pins: [M+, M-]

  MOT_B:
    type: 775 DC Blade Motor
    pins: [M+, M-]

  RELAY_CHG:
    type: LY2NJ DPDT Relay (Charging)
    pins: [COIL_A, COIL_B, COM1, NC1, NO1, COM2, NC2, NO2]

  PLATE:
    type: Copper Charging Contacts
    pins: [POS, NEG]

  BATT:
    type: LiFePO4 Battery Pack
    pins: [B+1, B+2, B+3, B+4, B+5, B-1, B-2, B-3, B-4, B-5]

  BUCK:
    type: 5V Buck Converter
    pins: [VIN+, VIN-, VOUT+, VOUT-]

cables:
  W_BATT:
    gauge: 14 AWG
    length: 0.3
    colors: [RD, BK]
  W_BATT_L:
    gauge: 14 AWG
    length: 0.2
    colors: [RD, BK]
  W_BATT_R:
    gauge: 14 AWG
    length: 0.2
    colors: [RD, BK]
  W_BATT_B:
    gauge: 14 AWG
    length: 0.2
    colors: [RD, BK]
  W_BATT_NEG:
    gauge: 14 AWG
    length: 0.2
    wirecount: 1
    colors: [BK]
  W_BTS_EN:
    gauge: 26 AWG
    length: 0.2
    colors: [RD, BK]
  W_PWR_5V:
    gauge: 22 AWG
    length: 0.3
    colors: [RD, BK]
  W_SPI:
    gauge: 26 AWG
    length: 0.2
    colors: [RD, BK, BU, GN, YE, OG, VT, GY]
  W_UART_GPS:
    gauge: 26 AWG
    length: 0.3
    colors: [RD, BK, GN, BU]
  W_UART_CAM:
    gauge: 26 AWG
    length: 0.2
    colors: [RD, BK, GN, BU]
  W_I2C:
    gauge: 26 AWG
    length: 0.2
    colors: [RD, BK, BU, GN]
  W_SONAR:
    gauge: 26 AWG
    length: 0.2
    colors: [RD, BK, OG, YE]
  W_BUMP:
    gauge: 26 AWG
    length: 0.3
    colors: [BU, GN, YE, OG, BK]
  W_BTS_L:
    gauge: 26 AWG
    length: 0.2
    colors: [RD, BK, BU, GN, YE, OG]
  W_BTS_R:
    gauge: 26 AWG
    length: 0.2
    colors: [RD, BK, BU, GN, YE, OG]
  W_BTS_B:
    gauge: 26 AWG
    length: 0.2
    colors: [RD, BK, BU]
  W_MOT_L:
    gauge: 16 AWG
    length: 0.2
    colors: [RD, BK]
  W_MOT_R:
    gauge: 16 AWG
    length: 0.2
    colors: [RD, BK]
  W_MOT_B:
    gauge: 16 AWG
    length: 0.2
    colors: [RD, BK]
  W_RELAY:
    gauge: 26 AWG
    length: 0.2
    colors: [RD, BK]
  W_CHG:
    gauge: 14 AWG
    length: 0.2
    colors: [RD, BK]
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

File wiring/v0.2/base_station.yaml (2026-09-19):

metadata:
  title: Base Station
  description: >
    Charging base station. Contains an ESP32-C3 and CC1101
    915 MHz transceiver for communication, a 14.6 V 10 A
    LiFePO4 battery charger, and a DPDT relay that switches
    the charger output onto the copper charging plate.
    A QR code marker is mounted on top for the mower bot's
    camera base finder, and an acrylic dome covers the
    electronics.

connectors:
  ESP32C3:
    type: ESP32-C3 Dev Board
    pins:
      - 5V
      - 3V3
      - GND1
      - GND2
      - GND3
      - GPIO4
      - GPIO5
      - GPIO6
      - GPIO7
      - GPIO8
      - GPIO9
      - GPIO10
  CC1101:
    type: CC1101 915 MHz RF Transceiver
    pins: [VCC, GND, SI, SO, SCLK, CSN, GDO0, GDO2]
  CHARGER:
    type: 14.6V 10A LiFePO4 Battery Charger
    pins: [AC_L, AC_N, DC_V+, DC_V-]
  RELAY:
    type: LY2NJ DPDT Power Relay
    pins: [COIL_A, COIL_B, COM1, NC1, NO1, COM2, NC2, NO2]
  PLATE:
    type: Copper Charging Plate
    pins: [POS, NEG]
  PSU:
    type: 5V USB Power Supply
    pins: [5V, GND]

cables:
  W_PWR:
    gauge: 26 AWG
    length: 0.2
    colors: [RD, BK]
  W_SPI:
    gauge: 26 AWG
    length: 0.15
    colors: [RD, BK, BU, GN, YE, OG, VT, GY]
  W_RELAY:
    gauge: 26 AWG
    length: 0.2
    colors: [RD, BK]
  W_CHG:
    gauge: 14 AWG
    length: 0.3
    colors: [RD, BK]
  W_PLATE:
    gauge: 14 AWG
    length: 0.3
    wirecount: 1
    colors: [RD]

connections:
  # --- 5 V power to ESP32-C3 ---
  - [PSU: 5V,  W_PWR: 1, ESP32C3: 5V]
  - [PSU: GND, W_PWR: 2, ESP32C3: GND1]

  # --- CC1101 SPI link ---
  - [ESP32C3: 3V3,   W_SPI: 1, CC1101: VCC]
  - [ESP32C3: GND2,  W_SPI: 2, CC1101: GND]
  - [ESP32C3: GPIO4, W_SPI: 3, CC1101: SI]
  - [ESP32C3: GPIO5, W_SPI: 4, CC1101: SO]
  - [ESP32C3: GPIO6, W_SPI: 5, CC1101: SCLK]
  - [ESP32C3: GPIO7, W_SPI: 6, CC1101: CSN]
  - [ESP32C3: GPIO8, W_SPI: 7, CC1101: GDO0]
  - [ESP32C3: GPIO9, W_SPI: 8, CC1101: GDO2]

  # --- Relay coil driven by ESP32-C3 ---
  - [ESP32C3: GPIO10, W_RELAY: 1, RELAY: COIL_A]
  - [ESP32C3: GND3,   W_RELAY: 2, RELAY: COIL_B]

  # --- Charger DC output -> relay -> copper plate ---
  - [CHARGER: DC_V+, W_CHG: 1, RELAY: COM1]
  - [CHARGER: DC_V-, W_CHG: 2, PLATE: NEG]
  - [RELAY: NO1,     W_PLATE: 1, PLATE: POS]

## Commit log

2026-09-20 wiring diagrams
2026-09-20 more examples
    [1946.3mf, BASE MINI L.3mf, BASE MINI R.3mf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]
2026-11-05 board backups
